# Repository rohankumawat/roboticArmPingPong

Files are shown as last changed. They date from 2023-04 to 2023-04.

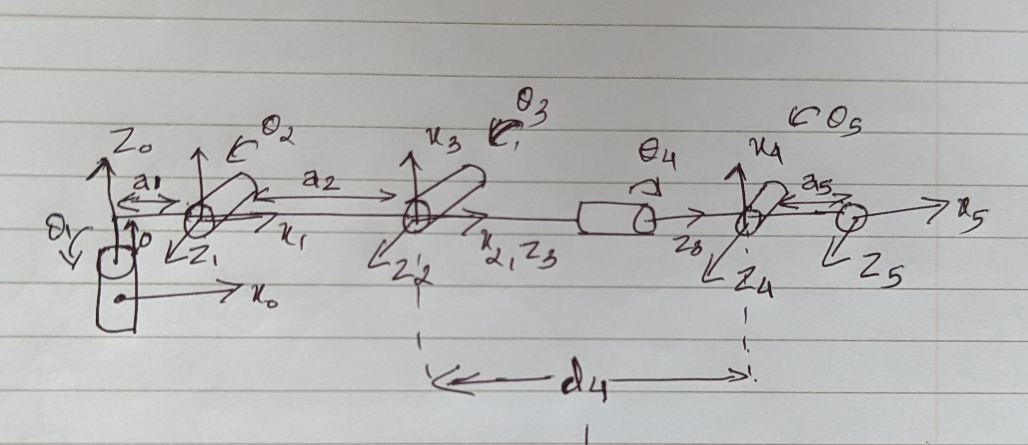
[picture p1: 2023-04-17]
D-H-Table/KinematicDiagram.jpg

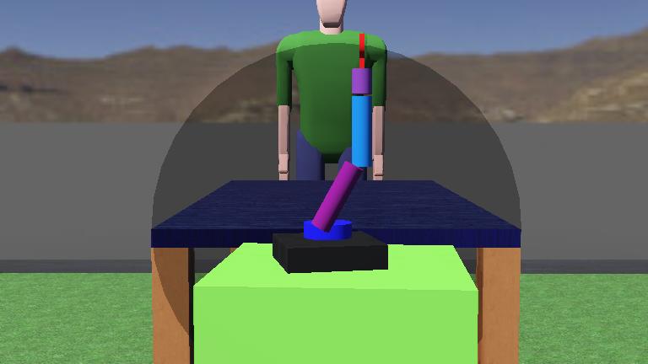
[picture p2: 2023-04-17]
WebotEnv/ManipulatorEnv_v2/worlds/.pingPong.jpg

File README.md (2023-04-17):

<p align="center">
 
 
<p>Rago is a robotic arm which is designed to play table tennis in real-time by tracking the ball's trajectory and hitting the ball if its within its proximity. Our journey begins by solving the kinematics equation, finding the trajectory for each joint, 3D printing of robotic arm, assembling of parts, and tracking of the ball in realtime. It has been equiped with camera sensor and machine learning algorithm to track the ball. It runs on Raspberry Pi 4B with Raspbian OS</p>
<br>

## CONTRIBUTORS
<ul><li>Athul Prasad Prasad Geetha - @thelastsayian</li>
<li>Aishwarya Palit - @aish0512</li>
<li>Gaurav Madihalli Sreekantegowda - @gauravam</li>
<li>Rohan Kumawat</li>
</ul>
<br>

## DEPENDENCIES

To build and run 'Rago', you need the following dependencies:

- CMake (2.8 or greater)
- OpenCV (4.5 or greater)
- Wiring Pi
- Eigen 

- To do anything further, clone this repository to your Raspberry Pi using the `git clone` command or by downloading the repository as a .zip file.
```
>$ https://github.com/rohankumawat/roboticArmPingPong.git
```

- Navigate to the 'roboticArmPingPong' directory.
```
>$ cd roboticArmPingPong
```
- Make the ``` dependency.sh ``` executable.
```
>$ chmod +x dependency.sh
```
- Now run the executable.
```
>$ ./dependency.sh
```

<br>

## Installation

- Navigate to the 'roboticArmPingPong' directory. 
 ``` 
 >$ cd roboticArmPingPong
  ```

```
- Run `cmake .` to generate the Makefile
- Run `make` to compile the source code
- Run `./roboticArmPingPong` to start the program
```
```
>$ cmake ..
>$ make
>$ ./roboticArmPingPong
```
<br>

## Document

https://github.com/rohankumawat/roboticArmPingPong/blob/main/document/RealTime%20Embedded%20Programming.docx

<br>

## Social Media
Twitter: https://twitter.com/TeamRago<br>
Instagram: https://instagram.com/rago_the_robo

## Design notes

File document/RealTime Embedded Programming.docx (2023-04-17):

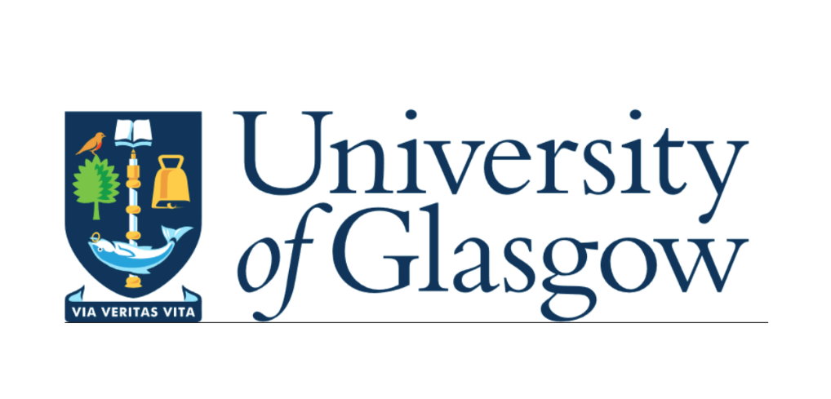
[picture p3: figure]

# ENG5220: Real Time Embedded Programming

# Team – 11

NAME | ID
Athul Prasad Prasad Geetha | 2789738P
Gaurav Madihalli Sreekantegowda | 2809092M
Aishwarya Palit | 2808985P
Rohan Kumawat | 2771441K

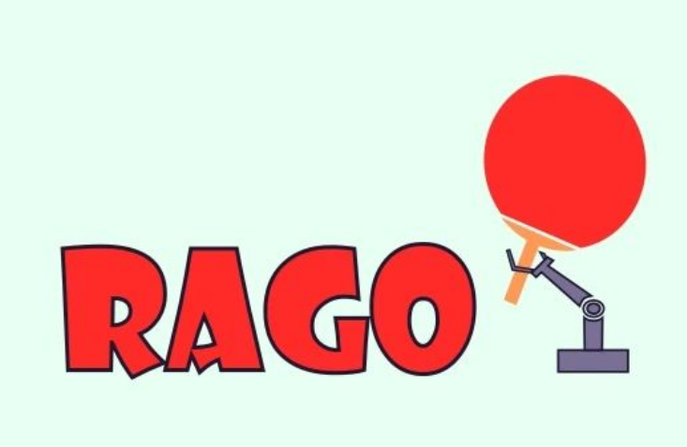
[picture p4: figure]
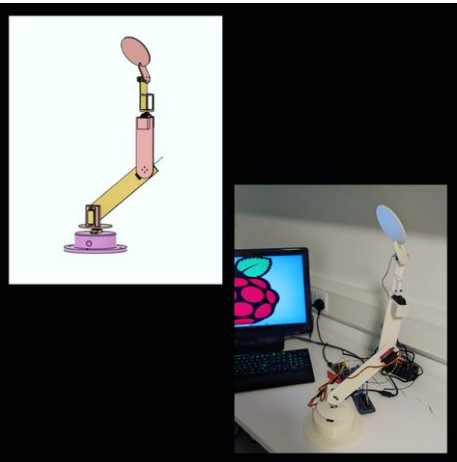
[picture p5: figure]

# Introduction

This project is about building a robotic arm which is equipped with a camera sensor and machine learning algorithms, our robot is designed to play table tennis in real-time by tracking the ball's trajectory and hitting the ball if its within its proximity.

Our project is divided into two parts – 1) Building of Robotic Arm and 2) Ball tracking and trajectory generation.

1) Building Robotic Arm

Below are the steps we follow to build our robotic arm:

a) Determine the requirements and specifications of the robotic arm:

To design any robotic arm, the basic criteria is the purpose. We choose this project as this is one of the real time embedding projects which can be useful in sports training, where athletes can practice against a reliable opponent. Next step is to determine the size, weight, payload capacity, and range of motion of the robotic arm. This information will help you choose the appropriate materials, components, and tools needed to build the arm.

b) Design the robotic arm:

The next step is to design of robotic arm. We designed the robotic arm in Fusion 360. We have decided about the number of joints, type of actuators, sensors, and control system in that phase. We have designed our robotic arm with 5 degrees of freedom.

Fig.1 CAD Model

c) Choose the components:

Select the appropriate components such as motors, sensors, controllers, and power supply based on the specifications and design of the robotic arm. For the actuation of the robot, we choose servo motors because servo motor is designed to provide precise control of its angular position, speed, and torque. They provide precise control of the arm's movements, allowing the arm to move and manipulate objects with precision and accuracy.

d) Solving kinematics of robotic arm:

The kinematics of a robotic arm describes the motion of its joints and the position and orientation of its end effector, which is the device or tool attached to the end of the arm. The kinematics of a robotic arm is important for understanding how the arm moves and how it can manipulate objects in space.

There are two types of kinematics that are commonly used in robotics: forward kinematics and inverse kinematics.

Forward kinematics is the process of determining the position and orientation of the end effector of a robotic arm given the joint angles. It involves calculating the transformation matrix that relates the position and orientation of the end effector to the joint angles. This is often represented by a mathematical model or algorithm that maps the joint angles to the end effector's position and orientation.

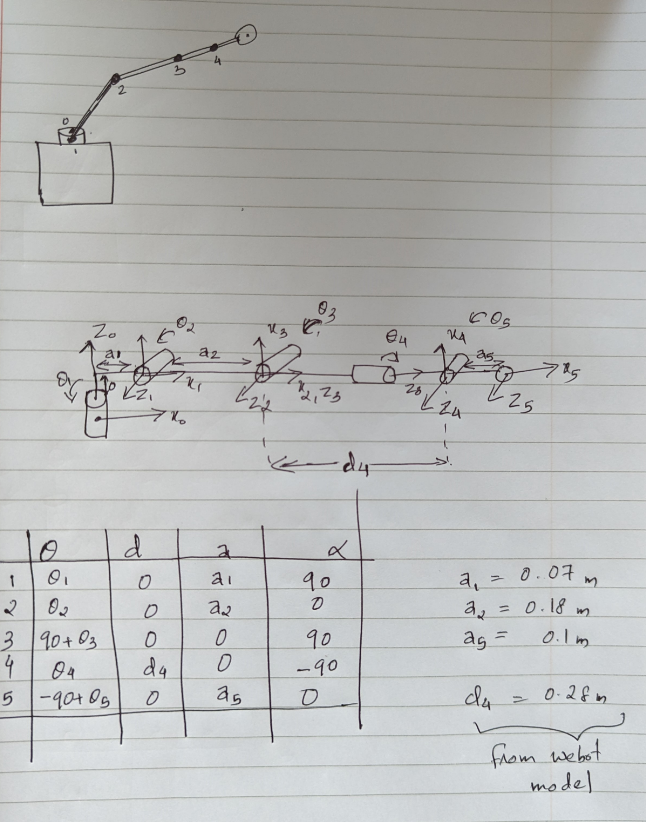
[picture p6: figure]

Fig.2 D-H Table and Forward Kinematics

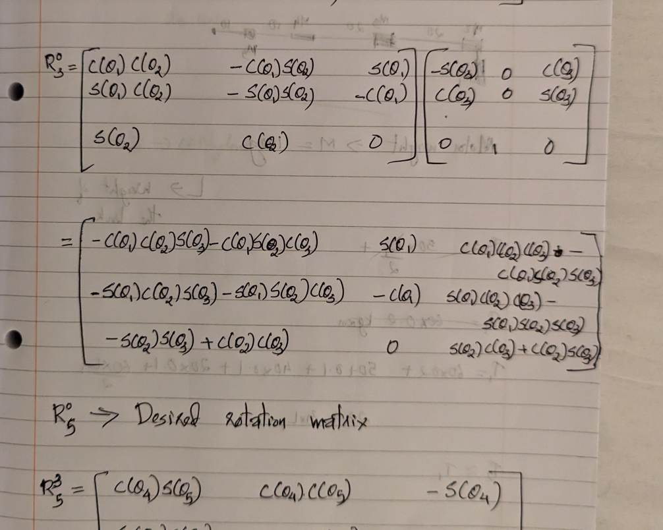
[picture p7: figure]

Fig.3 Inverse Kinematics Equation

e) Simulation of Robotic Arm:

Once the CAD model is ready, we have imported the CAD model and simulate it in Webot in C++. Simulation allows robotics engineers to design and optimize the robot's mechanical and control systems without the need for physical prototypes. This can save time and reduce costs associated with building and testing physical prototypes.

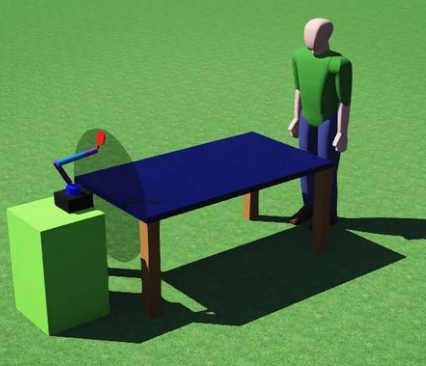
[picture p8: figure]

Fig.4 Simulation in Webot

f) 3D printing the parts:

You need to fabricate the parts of the robotic arm using tools such as 3D printers, CNC machines, or manual machining tools. It's important to ensure that the parts are precise and fit together correctly.

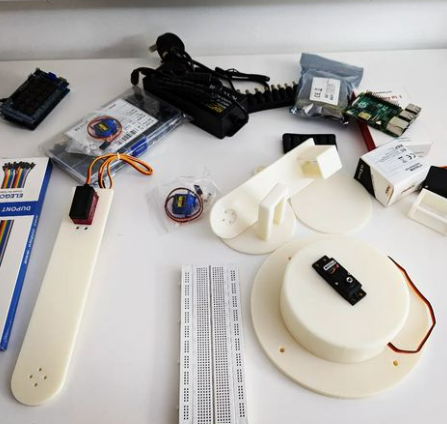
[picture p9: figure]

Fig.5 3D-Print Materials

g) Assemble the robotic arm:

You need to assemble the parts of the robotic arm using fasteners such as bolts, screws, or adhesives. You should test the arm's functionality at each stage of the assembly process.

h) Trajectory of Robotic Arm:

The trajectory of a robotic arm refers to the path followed by its end effector as it moves through space to complete a task or reach a specific target. The trajectory is determined by the motion of the arm's joints and can be controlled by the robot's control system.

To determine the trajectory of a robotic arm, the kinematics of the arm are first calculated. This involves determining the joint angles and positions required to move the end effector from one position to another. The desired trajectory can be programmed into the control system of the robot or can be generated in real-time based on feedback from sensors or other inputs.

There are different types of trajectories that can be used to control the motion of a robotic arm, depending on the task at hand. We have used Joint Space Trajectory.

Joint space trajectory refers to the path followed by the joints of a robotic arm as it moves through space to complete a task or reach a specific target. It is also known as joint space motion or joint space planning.

In joint space trajectory planning, the path of the end effector is specified in terms of the desired positions and orientations of the end effector at various points in time. These positions and orientations are then converted into joint angles that correspond to the movement of the robotic arm's individual joints.

i) Program the robotic arm:

You need to write the code that controls the robotic arm's movements and behaviour. Once you get the trajectory generation, you can code the servo motors based on your trajectory generation.

j) Test and calibrate the robotic arm:

You need to test the robotic arm's performance and calibrate the sensors and actuators to ensure that they work properly. You should also test the arm's safety features and make any necessary adjustments.

2) Ball tracking and trajectory generation

In this part, we have placed two cameras, one at the right side of the robotic arm and another one at the top. The side camera will track the projectile motion of the ball and top camera will give the linear motion of the ball.

To calculate the projectile motion of the ball, we have used Polynomial Regression model of order 3 and for linear motion Linear Regression Model.

Polynomial Regression - In polynomial regression, a polynomial equation of a certain degree is fitted to the data points, with the aim of finding the best fit curve that passes through as many data points as possible. The degree of the polynomial equation is determined by the complexity of the data.

Polynomial regression is often used in machine learning and data analysis to model complex relationships between variables, particularly when the relationship is nonlinear. It can be used to predict future values of a dependent variable based on the values of one or more independent variables.

However, it is important to note that polynomial regression can be prone to overfitting, which is when the model is too closely fitted to the training data and does not generalize well to new data. To avoid overfitting, it is important to validate the model using techniques such as cross-validation and regularization.

In the case of the projectile estimation from the side view camera we are going to fit a polynomial curve of n=3 to estimate the co-responding next output values from the previous two values in the trajectory. This led to good estimation of the final trajectory estimation of the ball from side view.

Linear Regression - Linear regression is a statistical method used to model the relationship between a dependent variable and one or more independent variables. The goal of linear regression is to find the best-fit line or plane that can explain the variance in the dependent variable based on the values of the independent variable(s).

This algorithm is used for the front view camera in which the estimation is given out from a linear regression model for final movement it is merged with side view projection co-ordinates together to give a approximate estimate of the next position of the ball in the projectile.

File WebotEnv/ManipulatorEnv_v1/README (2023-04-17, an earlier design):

This dir contains the webot model of a 5-DOF robotic arm. 
The joints can be controlled using the numpad keys
Each joint is a revolute joint.
Joint 1 -> Keys 1,2
Joint 2 -> Keys 3,4
Joint 3 -> Keys 5,6
Joint 4 -> Keys 7,8
Joint 5 -> Keys 9,0
This can be used to add constraints and explore the work envelope and the dimensions required for the manipulator.

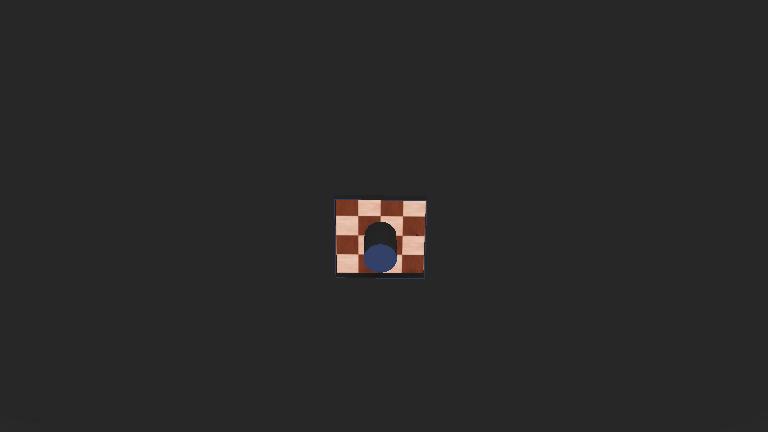
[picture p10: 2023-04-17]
WebotEnv/my_project/worlds/.pro.jpg

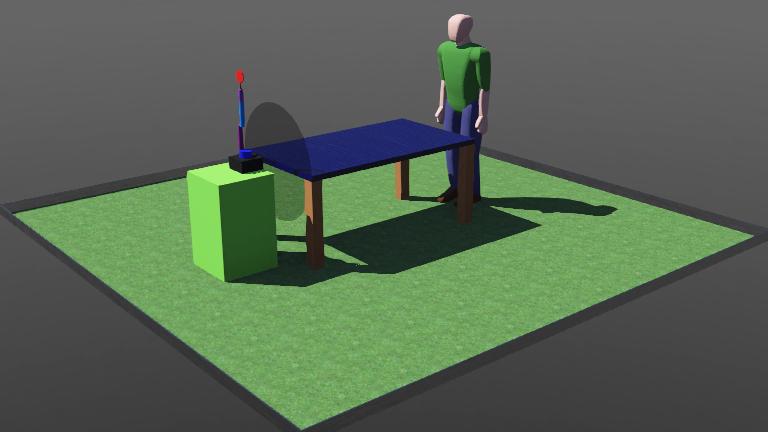
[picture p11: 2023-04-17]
WebotEnv/ManipulatorEnv_v2/Env.jpg

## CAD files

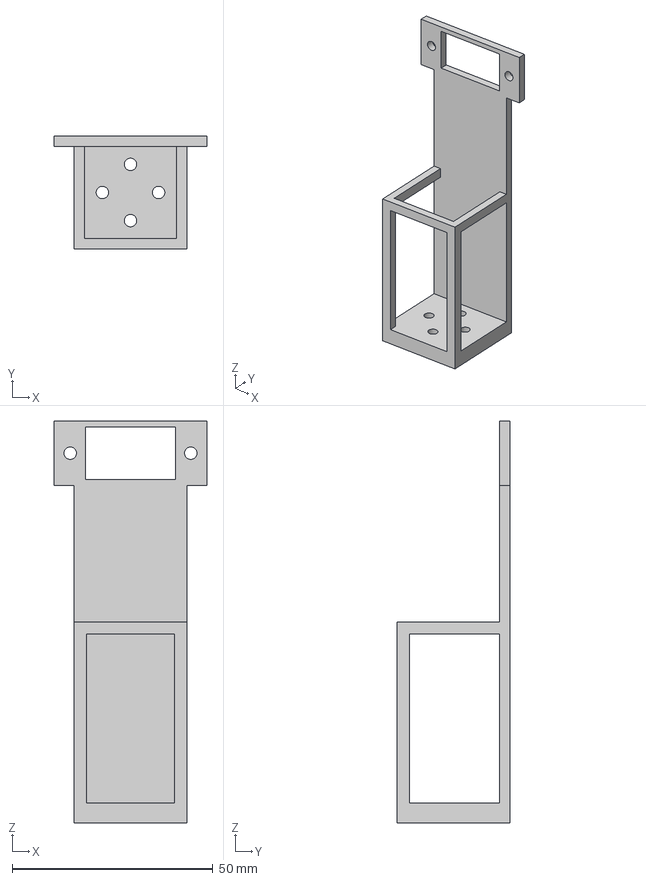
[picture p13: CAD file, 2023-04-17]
CAD/RAGO_Golden/STEP/Link4.step
38.0 x 28.0 x 100.0 mm

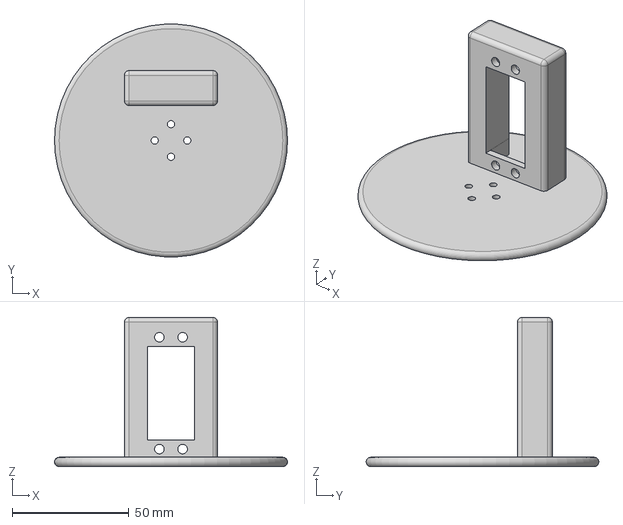
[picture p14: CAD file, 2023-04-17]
CAD/RAGO_Golden/STEP/Link1.step
100.0 x 99.8 x 64.0 mm

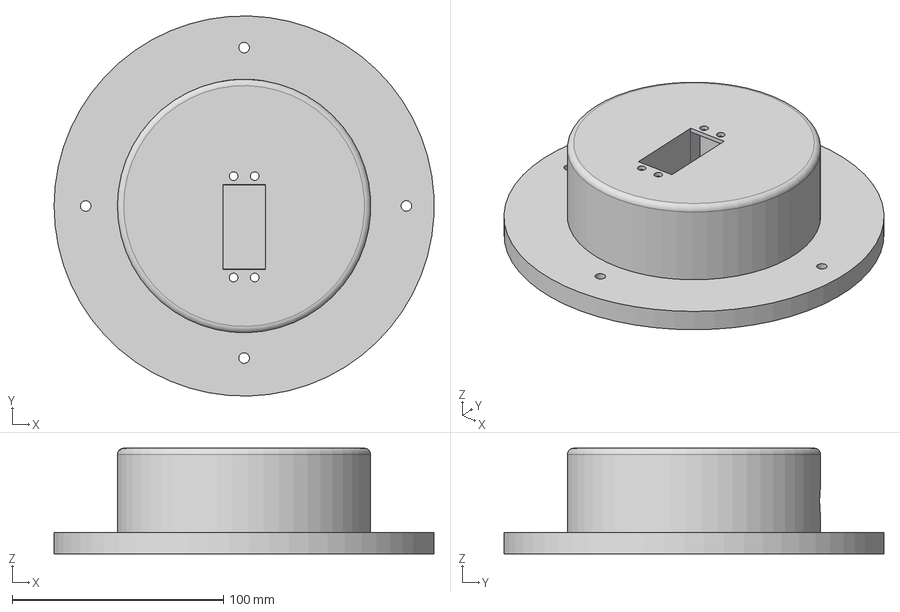
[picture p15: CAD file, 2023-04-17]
CAD/RAGO_Golden/STEP/Base.step
179.9 x 179.9 x 50.0 mm

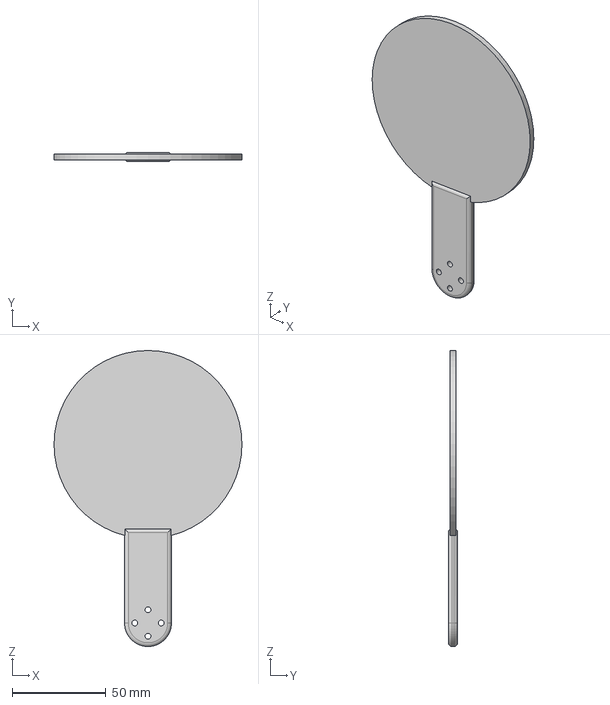
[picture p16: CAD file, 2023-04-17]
CAD/RAGO_Golden/STEP/EndEffector.step
100.0 x 5.00 x 157.5 mm

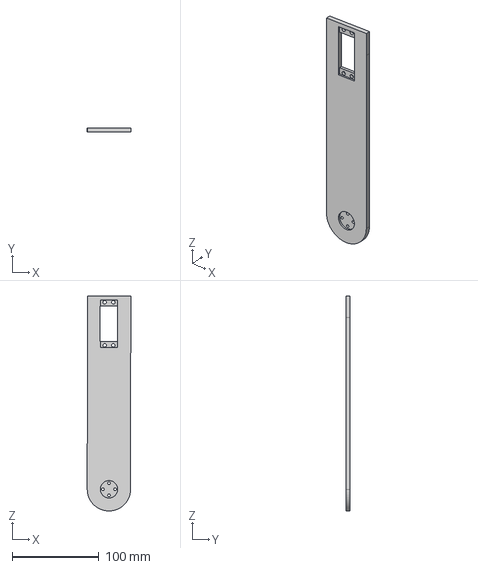
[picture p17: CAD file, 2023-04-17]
CAD/RAGO_Golden/STEP/Link2.step
50.2 x 5.00 x 247.5 mm

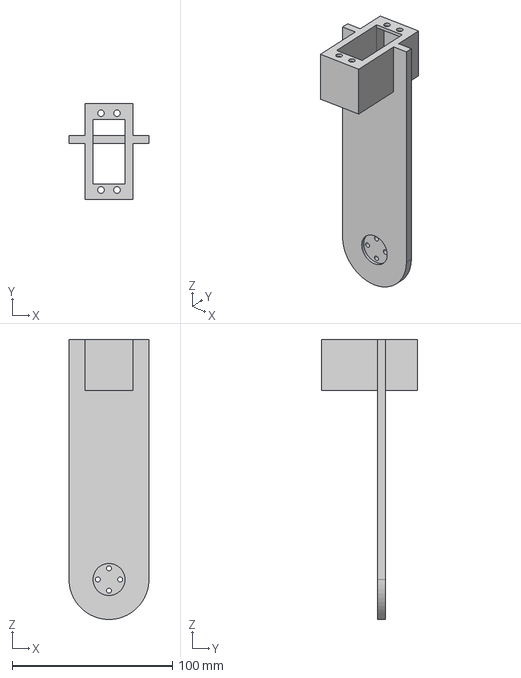
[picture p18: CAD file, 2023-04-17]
CAD/RAGO_Golden/STEP/Link3.step
50.0 x 60.0 x 175.0 mm

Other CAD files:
CAD/RAGO_Golden/STL/Base.stl
CAD/RAGO_Golden/STL/EndEffector.stl
CAD/RAGO_Golden/STL/Link1.stl
CAD/RAGO_Golden/STL/Link2.stl
CAD/RAGO_Golden/STL/Link3.stl
CAD/RAGO_Golden/STL/Link4.stl

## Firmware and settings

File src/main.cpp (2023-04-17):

#include <iostream>
#include <thread>
#include <atomic>
#include <wiringPi.h>
#include <softPwm.h>
#include <cmath>
#include <vector>

/*
 * User defined header files
 */

#include "trajectory_predictor.h"
#include "robot_arm.h"
#include "servo_func.h"
#include "mapping.h"

constexpr auto tf = 2.0;		                  // The motion should complete in 1second;
constexpr auto dt = 0.01;                         // Time steps;

#define M_PI 3.14159265358979323846 


std::vector<double> jointAngle;
std::vector<double> servoAngle;
std::vector<double> curAngle = {25,15,5,15,25};





void run(Robot_Arm& robotArm) {


    jointAngle = robotArm.getJointAngles();
    servoAngle = servoAngleMap(jointAngle);
    std::vector<double> jointPos;
    jointPos = robotArm.genTrajectory(curAngle, servoAngle, dt, tf);
    servoWrite(jointPos, dt, tf);

}



int main()
{

    void pwmDefine();

    std::vector<double> positionZ;
    std::vector<double> positionY;

    std::vector<double> pos(3,0.25);
   


    //Create instances of TrajectoryPredictor

    std::unique_ptr<TrajectoryPredictor> cap1 = std::make_unique<TrajectoryPredictor>(2); // SideCamera
    std::unique_ptr<TrajectoryPredictor> cap2 = std::make_unique<TrajectoryPredictor>(0); // BackCamera


    Robot_Arm robotArm(0.128, 0.25, 0.180);


    while (true)
    {

        // Initiate the trajectory prediction
        std::thread t1([&]() {
            positionZ = cap1->getPredictedTrajectory(0);
            });


        std::thread t2([&]() {
            positionY = cap2->getPredictedTrajectory(1);
            });


        t1.join();

        cap2->stopLoop();

        t2.join();


        //std::cout << "\nPrediction:\n ";
        //std::cout << positionZ[0] << " " << positionZ[1] << " " << positionZ[2]<< " " << positionZ[3] << "\n";
        //std::cout << positionY[0] << " " << positionY[1] << " " << positionY[2]<< " " << positionY[3]<< "\n";

        /*
         * Mapping from pixels to meters
         * Resolutuon used:
         */
        pos = getMapping(positionZ, positionY);

        std::cout << pos[0] << " " << pos[1] << " " << pos[2]<<"\n";

        robotArm.setPosition(pos[0], pos[1], pos[2]);

        std::thread t3(run, std::ref(robotArm));

        t3.join();


        int key = cv::waitKey(30);
        if (key == 27) {
        // Terminate the main function if the "Esc" key is pressed
        return 0;
    }
    }
}

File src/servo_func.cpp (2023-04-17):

#include <wiringPi.h>
#include <softPwm.h>
#include <cmath>
#include<vector>
#include <iostream>
#include <chrono>
#include <thread>


#include "servo_func.h"


#define M_PI 3.14159265358979323846 




void pwmDefine()
{


    pinMode(GPIO1, OUTPUT);
    digitalWrite(GPIO1, LOW);

    pinMode(GPIO2, OUTPUT);
    digitalWrite(GPIO2, LOW);

    pinMode(GPIO3, OUTPUT);
    digitalWrite(GPIO3, LOW);

    pinMode(GPIO4, OUTPUT);
    digitalWrite(GPIO4, LOW);

    pinMode(GPIO5, OUTPUT);
    digitalWrite(GPIO5, LOW);

    softPwmCreate(GPIO1, 0, 200);
    softPwmCreate(GPIO2, 0, 200);
    softPwmCreate(GPIO3, 0, 200);
    softPwmCreate(GPIO4, 0, 200);
    softPwmCreate(GPIO5, 0, 200);

}


std::vector<double> servoAngleMap(std::vector<double> jointAngles)
{
    // Angle mapping
    std::vector<double> servoAngle(5, 0.0);
    servoAngle[0] = -0.1111 * jointAngles[0] * 180 / M_PI + 25;
    servoAngle[1] = -0.1111 * jointAngles[1] * 180 / M_PI + 15;
    servoAngle[2] =  0.1111 * jointAngles[2] * 180 / M_PI + 5;
    servoAngle[3] = -0.1111 * jointAngles[3] * 180 / M_PI + 25;
    servoAngle[4] = -0.1111 * jointAngles[4] * 180 / M_PI + 15;

    return servoAngle;
}



void servoWrite(std::vector<double> jointPos, double dt, double tf)
{

    for (int i = 0; i < jointPos.size()/5; i++)
    {
        softPwmWrite(GPIO1, jointPos[i]);
        softPwmWrite(GPIO2, jointPos[i +   jointPos.size() / 5]);
        softPwmWrite(GPIO3, jointPos[i + 2*jointPos.size() / 5]);
        softPwmWrite(GPIO4, jointPos[i + 3*jointPos.size() / 5]);
        softPwmWrite(GPIO5, jointPos[i + 4*jointPos.size() / 5]);

        //std::cout << jointPos[i] << " " << jointPos[i + jointPos.size() / 5] << " " << jointPos[i + 2*jointPos.size() / 5] << " " << jointPos[i + 3*jointPos.size() / 5] << " " << jointPos[i + 4*jointPos.size() / 5] << "\n";
        
        std::this_thread::sleep_for(std::chrono::milliseconds(long(dt*1000))); // duration in milliseconds

    }
    std::this_thread::sleep_for(std::chrono::milliseconds(1000)); // duration in milliseconds

}

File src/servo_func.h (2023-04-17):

#ifndef SERVO_FUNC_H
#define SERVO_FUNC_H



/*
 * Define GPIO --> WiringPi
 */


#define GPIO1 17	// PIN 11/GPIO0
#define GPIO2 18	// PIN 12/GPIO1
#define GPIO3 23	// PIN 16/GPIO4
#define GPIO4 24	// PIN 18/GPIO5
#define GPIO5 4		// PIN 7/GPIO7

#include <wiringPi.h>
#include <softPwm.h>


void pwmDefine();
std::vector<double> servoAngleMap(std::vector<double> jointAngles);
void servoWrite(std::vector<double> jointPos, double dt, double tf);

#endif 
